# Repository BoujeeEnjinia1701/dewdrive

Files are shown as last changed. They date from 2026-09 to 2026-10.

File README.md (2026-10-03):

# DewDrive

     

**Area:** Water Security · **TRL:** 3 of 9 (proof of concept on paper) · **Value-engineering target:** $520 USD · **Difficulty:** 4 of 5

Solar-regenerated desiccant harvester that adsorbs moisture from air overnight and releases it into a passive condenser during the day.

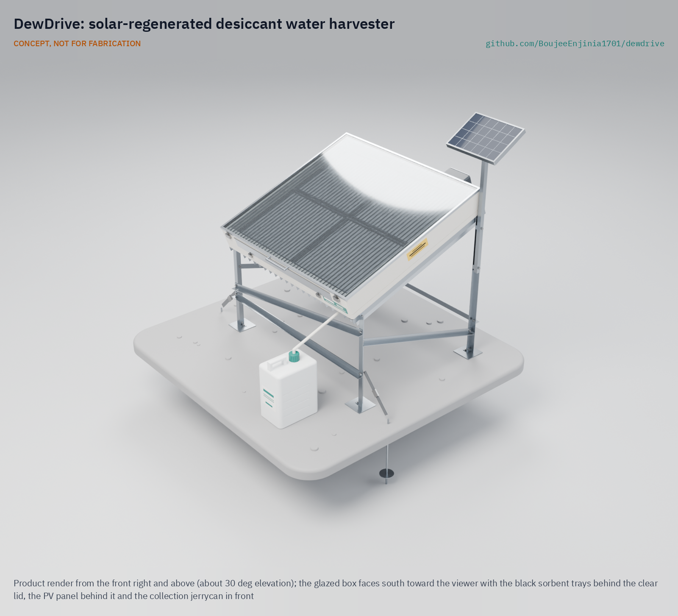
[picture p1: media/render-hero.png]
DewDrive: solar-regenerated desiccant water harvester, product render


[Exploded render](media/render-exploded.png) · [Detail render](media/render-detail.png) · [Interactive 3D model](media/viewer.html) · [Concept blueprint (PDF)](media/concept-blueprint.pdf) · [General arrangement DWD-DWG-001 (PDF)](cad/drawings/DWD-DWG-001.pdf) · [Sizing calculations](docs/04-calcs/01-sizing.md) · [Prototype build plan](docs/05-build-plan.md) · [Design decisions](docs/06-design-decisions.md) · [Review note](docs/REVIEW.md)

## Concept rationale

Cool desert nights are more humid than the days, and a salt-loaded desiccant can store that night-time moisture until the sun is strong enough to drive it out. DewDrive uses that daily rhythm directly: one glazed box that adsorbs at night and becomes a small solar still by day, with its own shaded floor as the condenser. It needs no compressor, no refrigerant and no grid, only a 2 W fan and the sun, and it keeps working at humidities where fog nets and dew condensers give nothing.

The design is open and garage-buildable on purpose. Silica gel and calcium chloride are sold as ordinary desiccants and food additives; the box is plywood, foam, polycarbonate and sheet aluminium; and the numbers behind every claim are in a script anyone can rerun. Commercial hydropanels are sealed products at about $2,000 each. An open design that a local workshop can build, repair and log lets communities and researchers compare real yields site by site.

## Burning platform

In 2022, 2.2 billion people still lacked safely managed drinking water, and 115 million collected untreated surface water from lakes, ponds, rivers and streams ([WHO, drinking-water fact sheet](https://www.who.int/news-room/fact-sheets/detail/drinking-water)). Over 2 billion people live in water-stressed countries, a pressure the WHO expects climate change and population growth to worsen in some regions (same source).

The cost falls hardest on the people who carry the water. UNICEF estimates that women and girls spend 200 million hours every day collecting it ([UNICEF, 2016](https://www.unicef.org/press-releases/unicef-collecting-water-often-colossal-waste-time-women-and-girls)). Even a supplementary half litre a day, made at the point of use, is water that nobody had to walk for.

## Where it could be used

### By industry

| Industry | Use |
| --- | --- |
| Humanitarian and WASH programs | Supplementary drinking water at schools, clinics and camps in arid areas, with logged yields to guide deployment |
| Agriculture and pastoralism | Drinking water at remote grazing posts and farm huts far from wells |
| Education and research | An open, instrumented test bed for sorbent and collector research across climates |
| Off-grid tourism and remote stations | Water for ranger posts, weather stations and eco-lodges supplied by truck |
| Emergency preparedness | A buildable backup source where wells or delivered supplies fail in drought |

### By country or region

| Country or region | Why it matters there |
| --- | --- |
| Navajo Nation, United States | About 30 % of homes lack running water, according to Navajo Nation Council Speaker Crystalyne Curley's testimony to the US Senate Committee on Indian Affairs on September 27, 2023 ([Senate Committee on Indian Affairs](https://www.indian.senate.gov/hearings/oversight-hearing-on-water-as-a-trust-resource-examining-access-in-native-communities/); [Native News Online](https://nativenewsonline.net/currents/senate-committee-on-indian-affairs-hears-30-of-navajo-nation-homes-lack-running-water)); a high-income country with households that haul water |
| Jordan | One of the most water-scarce countries in the world, with about 61 m³ of renewable water per person per year against a 500 m³ minimum ([UNICEF Jordan](https://www.unicef.org/jordan/water-sanitation-and-hygiene)) |
| Arid and semi-arid counties, Kenya | Access to safe water and basic sanitation is lowest in the arid and semi-arid land (ASAL) counties, where UNICEF focuses its water work with the government ([UNICEF Kenya](https://www.unicef.org/kenya/water-sanitation-and-hygiene)) |
| Rajasthan, India | In Thar Desert villages of northwest Rajasthan, water is scarce for up to 11 months of the year; women walk up to 4 km to fetch it, and villages store rainwater in underground taankas ([Al Jazeera, 2015](https://www.aljazeera.com/gallery/2015/11/19/women-lead-the-way-out-of-poverty-in-an-indian-desert)) |
| Atacama, Chile | In Alto Hospicio, only 1.6 % of informal settlements are connected to the water network and 75.4 % receive water by truck; researchers are assessing fog collection there as a complementary source ([Carter et al., *Frontiers in Environmental Science*, 2025](https://doi.org/10.3389/fenvs.2025.1537058)) |

## What sparked the idea

The starting point was a wartime device: the inflatable solar still that Mária Telkes developed at MIT during the Second World War for aircrews downed at sea. Seawater evaporated inside a balloon-like plastic envelope that folded into a package the size of a paper cup, and condensed again as drinkable water. The US government ordered 100,000 of them; by the summer of 1945 none had been delivered and the still was not used in the war, but solar stills later became part of military emergency kits ([USPTO, "A solar life"](https://www.uspto.gov/learning-and-resources/journeys-innovation/historical-stories/solar-life)). Telkes later patented a collapsible still, erected by inflation, as emergency equipment for the occupants of life rafts ([US Patent 3,415,719](https://patents.google.com/patent/US3415719A/en)). It showed that sunlight, a transparent envelope and a cool condensing surface can make drinkable water with no fuel at all. Telkes's still needed seawater. DewDrive asks what the same daytime still could do far from any sea, if a desiccant bed filled itself overnight from the desert air.

## Problem

Arid households without surface water or groundwater within reach depend on carried or trucked water; the air above them is an untapped supplementary source. Even desert air holds about 7 g of water per cubic metre on a 40 % RH night. Commercial solar hydropanels cost about $2,000 each and cannot be built or repaired locally. Design with, not for: requirements must come from co-design sessions and field trials with the intended users through a local partner.

Problem statement: [docs/01-problem.md](docs/01-problem.md)

## Concept

A glazed, insulated box 1.1 x 1.0 m, tilted 20° toward the sun, holds 4 kg of silica gel impregnated with 25 wt % calcium chloride in four sealed trays. At night the vent flaps are opened and a small solar-powered fan draws air in above the trays and down through the sorbent beds; the fan stops if the air goes above 70 % RH. By day the flaps are shut, the sun heats the sorbent to about 112 °C, and the vapour passes a black drip screen, condenses on the shaded, finned floor of the box and drains into a bottle. TRL 3 calculations ([DWD-CAL-001](docs/04-calcs/01-sizing.md)) for the design decided on 2026-09-25 ([DWD-DDR-002](docs/decisions/0002-recommendations-accepted.md)), made buildable in [DWD-DDR-003](docs/decisions/0003-design-for-construction.md), give:

| Quantity | Estimate |
| --- | --- |
| Water at 40 % night RH | about 0.57 L per day (target 0.5 L) |
| Water at 25 % night RH | about 0.45 L per day (target 0.25 L) |
| Mass | about 60 kg dry; box about 35 kg, 23 kg with the trays and deck lifted out |
| Parts cost | Estimated $639 for the buildable design, $119 over the $520 value-engineering target (a hypothetical control target, not a limit) |

One unit is a supplement: about one fifth of one person's survival drinking need.

Full design precis: [docs/02-concept.md](docs/02-concept.md)

## Key components

- Silica gel and calcium chloride composite sorbent in four black, sealed trays, with air drawn through the beds at night
- Drip screens with brine sumps under the trays
- Glazed, insulated solar box on a tilted steel stand
- Finned aluminium condenser forming the shaded floor of the box
- Night fan with a 10 W PV panel and a small LiFePO4 battery
- Humidity and temperature logging

The priced bill of materials is in [bom/bom.csv](bom/bom.csv). The parametric model is [cad/src/model.py](cad/src/model.py), with STEP files in `cad/step/`.

## Building the prototype

The prototype build plan ([docs/05-build-plan.md](docs/05-build-plan.md)) shows how to make each of the 31 components and put them together, with a making sketch for every made part, close-ups of the joints and a picture for every assembly step. Making the concept buildable added the parts that hold it together: battened wall panels, a lift-out tray deck that carries the drip screens, a fan hood that is now the only outlet, and a bolted, braced stand ([DWD-DDR-003](docs/decisions/0003-design-for-construction.md)). The water and heat results are unchanged; the parts now cost about $620, over the $520 value-engineering target, and the full box weighs 35.2 kg; Amish restated the portability requirement on 2026-10-02 for a lift with the trays and deck taken out (23.4 kg). Both are recorded in the [design decisions register](docs/06-design-decisions.md). It is a plan only: building and testing to it is TRL 4 work.

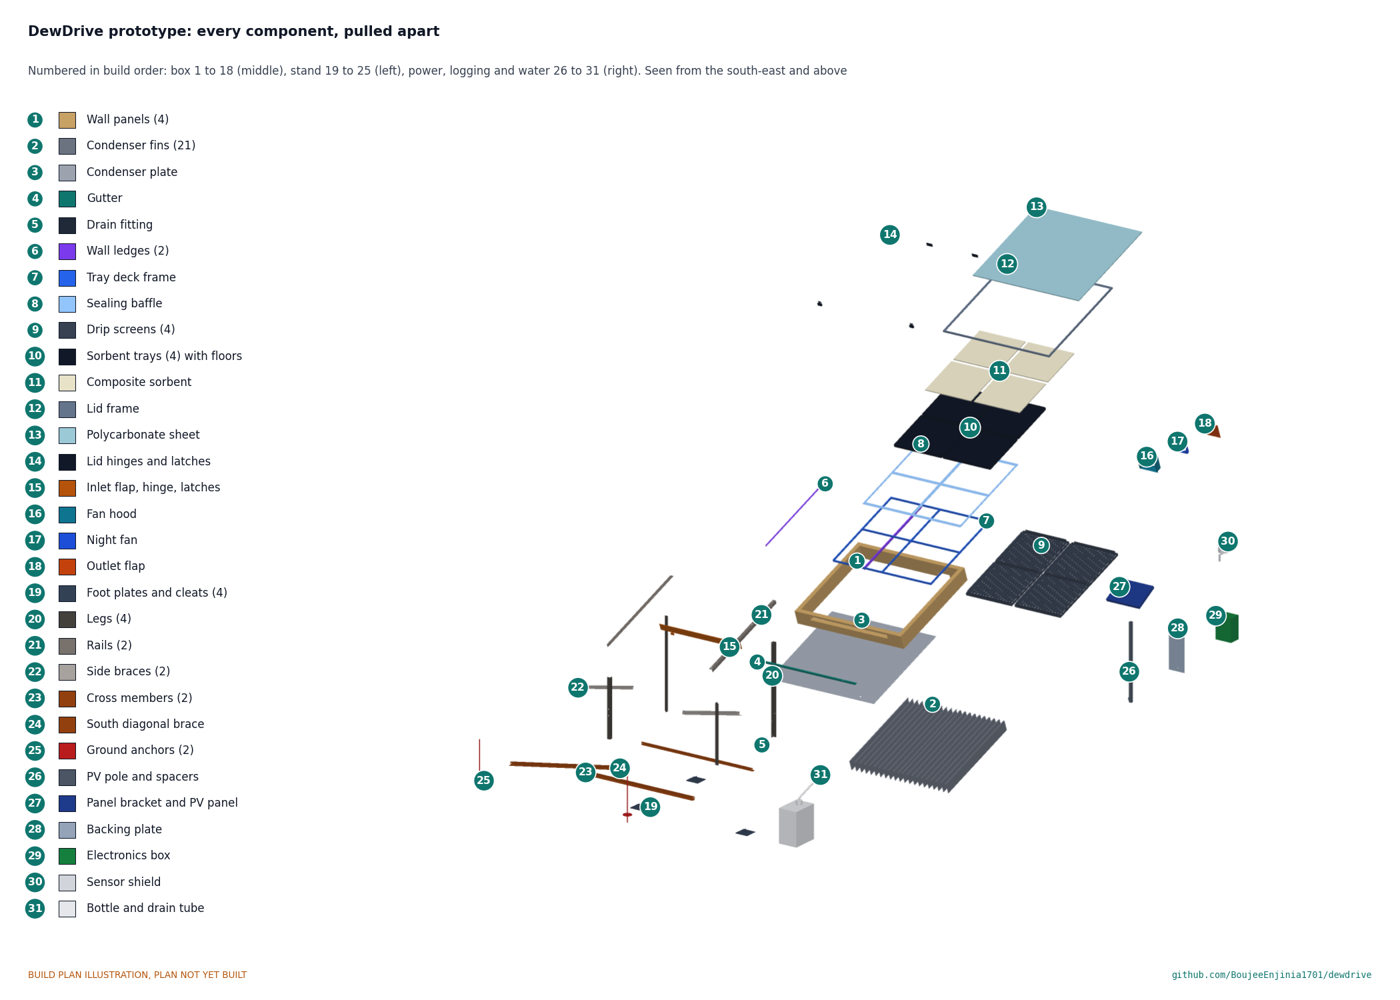
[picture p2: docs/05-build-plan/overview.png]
DewDrive prototype: every component pulled apart and numbered in build order


## Safety

> **Safety:** Harvested water must be tested and treated before drinking. The box interior and glazing get hot enough to burn, calcium chloride irritates eyes and skin, the small lithium iron phosphate battery must be fused, and the tilted panel must be held down with two ground anchors (or about 40 kg of ballast) against wind. See the safety section of the [design precis](docs/02-concept.md).

## Repository layout

| Folder | Contents |
| --- | --- |
| `docs/` | Problem, concept, requirements, calculations and design decisions |
| `cad/src/` | build123d Python source, the source of truth for all geometry |
| `cad/step/`, `cad/stl/` | Exported models for FreeCAD, other CAD tools and printing |
| `cad/drawings/` | 2D sketches and dimensioned drawings |
| `bom/` | Bill of materials |
| `electronics/` | KiCad schematics and PCB layouts |
| `firmware/` | Microcontroller code |
| `media/` | Renders, perspectives and photos |
| `build-log/` | Dated prototyping notes |

## Documentation

Controlled documents follow the portfolio [documentation standard](.kit/STANDARDS.md). Each carries a document ID (DWD-PRC-001 for the precis), a version and a revision history. Branded PDFs are built with `python .kit/render.py` and attached to GitHub Releases when a document is tagged, for example `DWD-PRC-001/v1.0`.

## Credits

Designed by Amish Chadha. See [CONTRIBUTORS.md](CONTRIBUTORS.md) for roles. To cite this design, use [CITATION.cff](CITATION.cff) (GitHub shows it as "Cite this repository").

AI assistance (Claude) was used to accelerate concept renders, prototype documentation and first-pass sizing calculations. Design direction and all decisions are Amish Chadha's, recorded in this repository's decision records (`docs/decisions/`).

## Licenses

- **Hardware** (CAD, drawings, BOM, electronics): [CERN-OHL-S v2](LICENSE)
- **Software** (firmware, scripts, notebooks): [MIT](LICENSE-SOFTWARE)

A project of the [Design Molecule](https://designmolecule.com) lab.

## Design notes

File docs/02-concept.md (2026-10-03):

---
doc_id: DWD-PRC-001
title: DewDrive design precis
project: DewDrive
doc_type: Design precis
version: "0.9"
status: Draft
date: '2026-10-02'
author: Amish Chadha
license: CERN-OHL-S-2.0
revisions:
- version: "0.1"
  date: '2026-09-24'
  author: Amish Chadha
  change: Initial scaffold
- version: "0.2"
  date: '2026-09-25'
  author: Amish Chadha
  change: Populate to TRL 2 (how it works, components, first-order numbers, design choices, safety, open questions, media)
- version: "0.3"
  date: '2026-09-25'
  author: Amish Chadha
  change: TRL 3 update (design choices decided by Amish in DWD-DDR-001; numbers replaced by DWD-CAL-001; parametric model and drawing DWD-DWG-001; yield shortfall and proposed fixes)
- version: "0.4"
  date: '2026-09-25'
  author: Amish Chadha
  change: Recommendations accepted by Amish (DDR-002); through-flow trays, 25 wt % salt, drip screens, fan humidity cut-out, anchors as default; numbers from DWD-CAL-001 v0.2
- version: "0.5"
  date: '2026-09-26'
  author: Amish Chadha
  change: Budget top-up approved by Amish
- version: "0.6"
  date: '2026-10-01'
  author: Amish Chadha
  change: "Design made constructable (DWD-DDR-003): tray deck, one outlet through the fan hood, bolted stand; mass and cost from DWD-CAL-001 v0.4"
- version: "0.7"
  date: '2026-10-01'
  author: Amish Chadha
  change: Budget treated as a value-engineering target
- version: "0.8"
  date: '2026-10-02'
  author: Amish Chadha
  change: 'Decisions of 2026-10-02 carried in (DWD-DEC-001 items 2 to 5): glazing rated 130 °C or more, stagnation vent study, R9 restated with lifting rule, first partner type'
- version: "0.9"
  date: '2026-10-02'
  author: Amish Chadha
  change: 'Follow-ups carried out: vent study concluded (low-emissivity screens dropped), label and 130 °C glazing in the BOM, cost USD 639 against the USD 520 target'
---

# DewDrive design precis

DewDrive is a glazed, insulated box 1.1 x 1.0 m, tilted 20° toward the sun on a steel stand. Inside, four black trays hold 4 kg of silica gel impregnated with 25 wt % calcium chloride. At night the vent flaps are opened and a 2 W fan draws air in above the trays and down through their mesh floors, and the sorbent takes up water. In the morning the flaps are shut; the sun heats the bed to about 112 °C by noon and drives the vapour down past a black drip screen onto a finned aluminium floor that forms the condenser, shaded by the box itself. The condensate runs down the slope into a gutter and a 10 L bottle. The TRL 3 calculation (DWD-CAL-001 v0.2) gives about 0.57 L per day at 40 % night RH and 0.45 L at 25 %, meeting the 0.5 and 0.25 L targets. The design follows Amish's decisions of 2026-09-25 (DWD-DDR-002), which replaced the v0.1 layout that made only 0.20 L per day. Made buildable in DWD-DDR-003, the estimated parts cost is $620 against the $520 value-engineering target (moved to $520 by Amish on 2026-09-26), $100 over the target. One unit supplements drinking water; it does not replace a water supply.

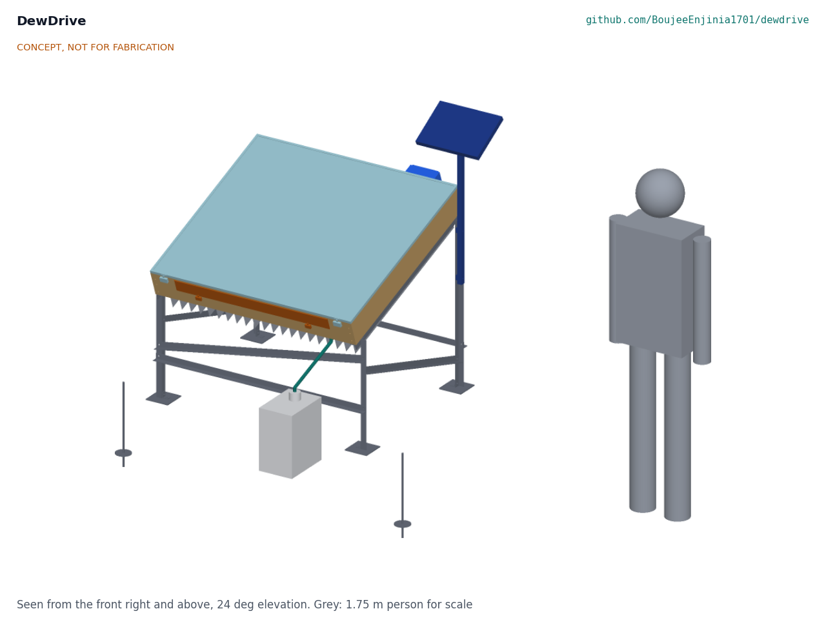
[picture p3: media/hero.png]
Hero render


*Figure 1. DewDrive on its stand, with a 1.75 m person for scale. Glazing faces south (for a northern-hemisphere site), the collection bottle sits below the low edge and the 10 W PV panel is on a pole to the north, where it cannot shade the box. Generated from the parametric model `cad/src/model.py`.*

## How it works

1. **Adsorb at night.** In the evening the user opens the south inlet flap, which sits above the tray deck, and the outlet flap over the fan on the north wall. The logger switches on the fan, which draws 40 m³/h of night air in over the trays, down through the 9.3 mm sorbent beds and their mesh floors, and out under the deck through a slot into the fan hood, for 10 h. The trays sit on an EPDM gasket on the sealing baffle of a lift-out deck, so the air cannot bypass the beds. The CaCl₂ in the silica gel pores binds water first as hydrates and then as a solution held in the pores; the silica gel adds a little uptake of its own and keeps the solution in place. If the air goes above 70 % RH the logger stops the fan.
2. **Seal and heat by day.** In the morning the user shuts both flaps. Sunlight passes through the twin-wall polycarbonate and heats the black top faces of the trays. The bed passes 89 °C by 09:00 and reaches about 112 °C at noon, and its vapour pressure rises above that of the condenser.
3. **Condense.** Vapour diffuses down through the 65 mm gap under the trays, around the drip-screen channels, to the aluminium floor plate, which stays within about 12 K of ambient thanks to 21 fins in the shade under the box.
4. **Collect.** Water films run down the 20° slope to a gutter along the low edge and drain through a silicone tube into a food-grade jerrycan.
5. **Log.** The logger records air temperature and RH, bed and condenser temperatures every 5 min, and applies the fan humidity cut-out; the user weighs the bottle each day. The data make yields comparable between sites.

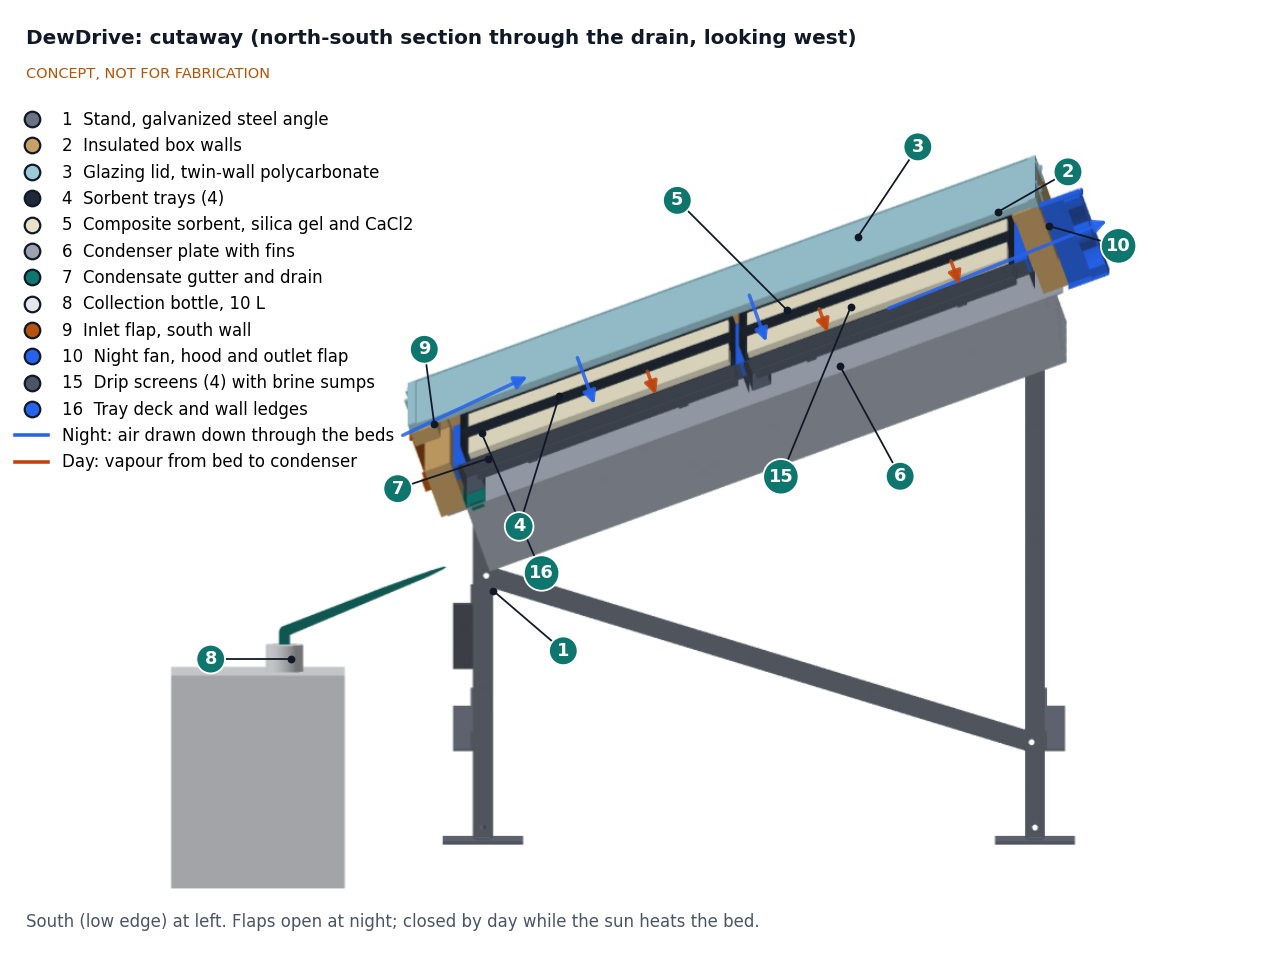
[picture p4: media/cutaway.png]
Cutaway


*Figure 2. North-south section through the drain, looking west. Blue arrows: night air path with the flaps open, in above the trays and down through the beds. Red arrows: daytime vapour path from the bed (5) past the drip screen (15) to the condenser floor (6). The gutter (7) along the low edge drains to the bottle (8).*

## Main components

Table 1. Main components. Numbers match `bom/bom.csv`, drawing DWD-DWG-001 and Figures 2 and 3.

| # | Component | Choice | Notes |
| --- | --- | --- | --- |
| 1 | Stand | Galvanized steel angle 30 x 30 x 3 mm, rails, legs, braces and cross members, bolted; tilt 20° | Separable from the box; two ground anchors by default, about 40 kg of ballast as the alternative (DWD-DDR-002, D13; DWD-CAL-001, H2 to H4) |
| 2 | Insulated box walls | Plywood skins with 25 mm PIR foam, 1,100 x 1,000 x 140 mm, 40 mm thick | Open top (glazing) and bottom (condenser) |
| 3 | Glazing lid | 10 mm UV-stabilized twin-wall polycarbonate, hinged on the north edge | Rated 130 °C or more; a 120 °C sheet only if supplier data and the inner skin measured at the TRL 4 stagnation test both show it stays inside its rating (DWD-DEC-001, item 3) |
| 4 | Sorbent trays (4) | Aluminium pans 490 x 430 x 25 mm with stainless mesh floors; black top, bare underside; EPDM edge gasket on a 1 mm aluminium sealing baffle | Lift out for recharging; the baffle forces the night air through the beds (D9) |
| 5 | Composite sorbent | 4 kg: 3.0 kg mesoporous silica gel with 1.0 kg CaCl₂ (25 wt %, D10) | Bed 9.3 mm deep on 0.785 m²; all food-grade |
| 15 | Drip screens (4) | Two staggered layers of 20 x 6 mm aluminium channels at 30 mm pitch under each tray, running down the slope to a closed brine sump; painted matt black | Catch any brine that leaves the beds (sumps 0.58 L in all) with no line of sight from bed to condenser (D11) |
| 6 | Condenser | 2 mm aluminium floor plate with 21 fins, 1 x 100 x 920 mm at 50 mm pitch | Wetted face food-safe coated |
| 7 | Gutter and drain tube | Gutter along the low edge; food-grade silicone tube | |
| 8 | Collection bottle | 10 L HDPE jerrycan | About 17 days of production at the design point |
| 9 | Vent flap, south inlet | Hinged flap 800 x 40 mm above the trays, with EPDM seal and latches | Closed by day; seal quality sets the vapour loss |
| 10 | Night fan, hood and outlet flap | 12 V 120 mm fan, about 2 W, in a hood over a slot in the north wall below the deck; the outlet flap closes the fan opening by day | Fan switched by the logger; stops above 70 % RH |
| 11 | PV panel | 10 W, 12 V, on a pole north of the box | Runs fan and logger |
| 12 | Electronics box | PWM charge controller, 12.8 V 6 Ah LiFePO4 with BMS, ESP32 logger | Only low-voltage DC on the device |
| 13 | Sensors | Air T and RH in a radiation shield; bed and condenser probes | The air RH reading drives the fan cut-out |

Item 14 (hardware and consumables) is in the BOM but not modelled. Item 16 is the lift-out tray deck with its sealing baffle and the wall ledges. The general arrangement is drawing DWD-DWG-001 Rev P4 (`cad/drawings/`); the STEP files are in `cad/step/`; how to build it is the build plan DWD-BLD-001 (`docs/05-build-plan.md`).

**Fan rule (DWD-DDR-002, D11).** The logger runs the fan from the evening flap opening for 10 h, and stops it whenever the air RH is above 70 % (restarting below about 65 %, to avoid cycling). This is a design rule for the firmware sketch; firmware beyond a sketch is TRL 4 work and on hold.

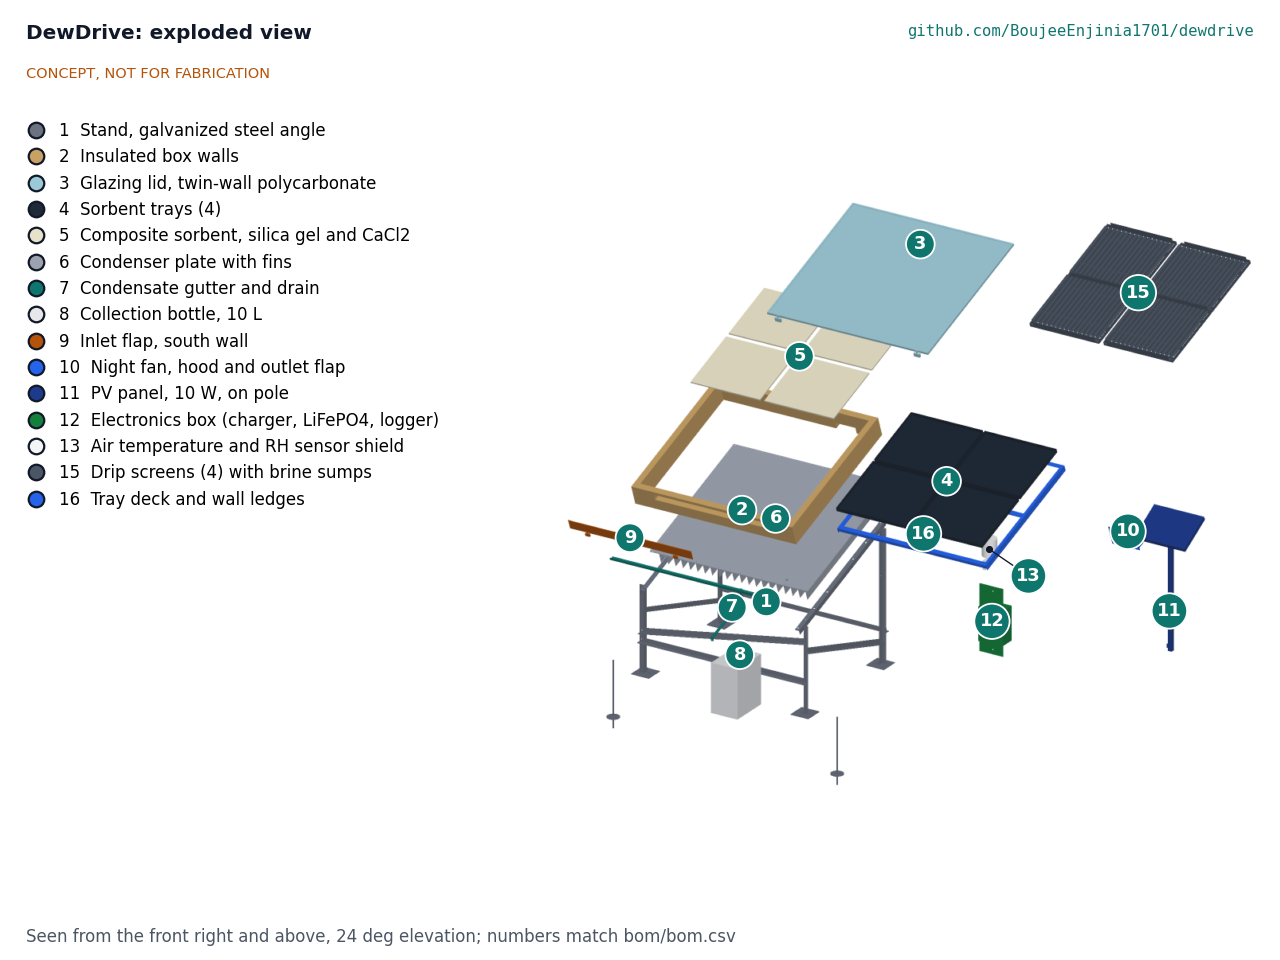
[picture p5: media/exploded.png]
Exploded view


*Figure 3. Exploded view with BOM numbers.*

## Numbers from DWD-CAL-001

All values are first-principles estimates from `docs/04-calcs/sizing.py` (DWD-CAL-001 v0.5); the tag after each value is the line of the script output that carries it. The sorbent isotherm is built from bulk salt data and must be replaced by measured isotherms of the actual composite.

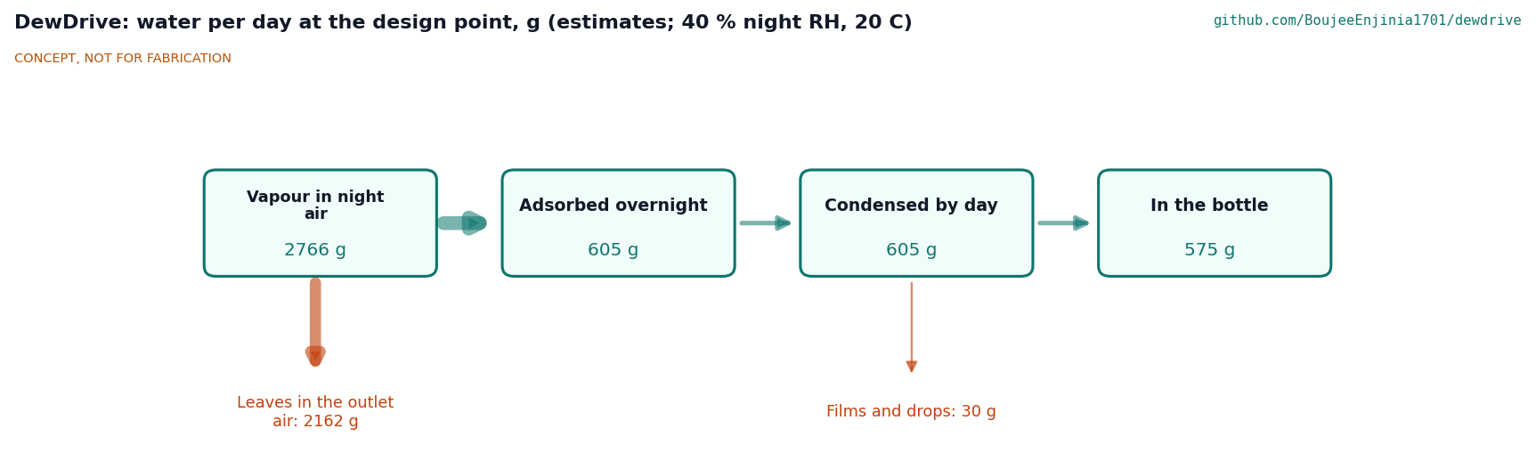
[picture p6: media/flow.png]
Water flow


*Figure 4. Water per day at the design point (40 % night RH, 20 °C). All values are estimates.*

Table 2. Water, energy, size and cost.

| Quantity | Value | Basis | Requirement |
| --- | --- | --- | --- |
| Vapour carried through the box overnight | 2.77 kg (B4) | 40 m³/h for 10 h at 6.92 g/m³ | |
| Share of the vapour driving force captured | Nearly all (gas-side NTU 19, B3) | Air drawn down through the bed; 0.16 Pa pressure drop | v0.1 layout: 11 % (B2) |
| Overnight uptake | 0.60 kg (B5) | Cyclic simulation; equilibrium would allow 1.59 kg (A4) | |
| Collected at 40 % night RH | 0.57 L per day (C3) | 0.60 kg condensed less 30 g of films | R1 met |
| Collected at 25 % night RH | 0.45 L per day (C4) | Same model | R2 met |
| Bed temperature at noon | 112 °C (C2) | 785 W/m² peak; 4.24 kWh/m² from 09:00 to 15:00 (C1) | R3 met |
| Condenser rise above ambient, peak | 12.1 K (C2) | Load 299 W peak; UA 24.6 W/K (C8) | R5 met |
| Where the sun goes | 3.68 kWh absorbed; 0.44 kWh desorbs water; 1.69 kWh lost through the glazing; 1.47 kWh to the condenser (C7) | The black drip screens cut the effective bed-to-condenser emissivity from 0.545 to 0.327 (C5) | |
| Solar-to-water efficiency | 7.1 % (C7) | Published devices reach about 9 % (LaPotin et al., 2021) | |
| Stagnation temperature, dry bed | 122 °C (D1) | Noon, 35 °C air | Glazing rated 130 °C or more (DWD-DEC-001, item 3) |
| Electrical use and supply | 23.6 Wh per day against 35 Wh (F1); 2.6 days of autonomy (F2) | Fan 2 W for 10 h; logger 0.15 W | R4 met |
| Salt containment | Pores fill above 71 % RH (E2); 43 % full after one 90 % RH night (E3) | Sumps 0.58 L (E6) | R7 met on paper |
| Mass | 60.2 kg (133 lb) dry; box 35.2 kg, 23.4 kg with the trays and deck lifted out (G1, G2) | Model components | R9 met as restated on 2026-10-02 (lift with the trays and deck out) |
| Wind at 20 m/s | 317 N normal to the lid; tips without two anchors or 40 kg of ballast (H1 to H4) | Force coefficient 1.2 on 1.1 m² | R10 not verifiable at TRL 3 |
| Parts cost | $639 (J1) | `bom/bom.csv` | R11 over the value-engineering target by $119 (target $520) |
| Water per dollar over 5 years | about $0.49 per litre (J2) | Parts only | For comparison |

What the numbers say:

- **Drawing the air through the bed fixes the yield.** The v0.1 layout, with air skimming past the trays, captured only 11 % of the vapour driving force and made 0.20 L per day. Through the bed, the air leaves close to equilibrium with the sorbent, and the day desorption now sets the limit. Even if slow diffusion inside the grains cut the night NTU to 1, the yield would still be 0.53 L per day (C9).
- **The drip screens help the yield.** Black channels under the trays catch brine and also cut the radiation from the hot beads to the condenser by about 40 %: 0.57 L per day with them against 0.51 L without (C6).
- **A low-emissivity screen would do more, but overheats the box.** Bare aluminium channels would give 0.82 L per day, but a dry bed would stagnate at about 166 °C, beyond the rating of polycarbonate glazing (C10, D1). That option is not adopted. Amish decided on 2026-10-02 (DWD-DEC-001, item 4) on one short paper study of a passive stagnation vent. The study (DWD-CAL-001, section D) finds that a vent of about 117 cm² would hold the dry bed at 122 °C, but it would have to stay shut in normal operation, when the bed already runs at 130 to 149 °C, so it needs a thermostat and is not passive or modest in cost. The low-emissivity screens are therefore dropped and the prototype keeps the black screens.
- **The lower salt loading contains the brine.** At 25 wt % the solution fills the pores only above 71 % RH, against 51 % RH at the v0.1 loading (E2).
- **Cost is over the value-engineering target once the design is buildable.** The gasket, baffle and drip screens added $27 (total $515, D15); the parts that make the design buildable (DWD-DDR-003) bring the estimated cost to $620; the 2026-10-02 decisions add a glazing sheet rated 130 °C or more and a label, making $639 against the $520 target ($119 over).
- **Yield is still modest.** About 0.57 L per day is about one fifth of one person's survival drinking need.

## Key design choices

Choices 1 to 7 were decided by Amish on 2026-09-25 (DWD-DDR-001, going with the recommendation), and choices 8 to 11 on the same day (DWD-DDR-002). Choice 12 was part of the design from the start.

1. **Single-stage, flat glazed box** rather than a dual-stage or tubular design (D4). Dual-stage could add about 20 % in later versions (LaPotin et al., 2021).
2. **Silica gel and CaCl₂ composite**, rather than MOF, zeolite or LiCl (D3), at 25 wt % salt (D10, amending the 33 wt % of D3).
3. **Condenser as the shaded floor of the box**, directly below the bed (D4). Short vapour path, no pump, one fewer seal.
4. **Fan-assisted night airflow** with a 10 W PV panel and a 12.8 V LiFePO4 battery, rather than natural airflow (D5).
5. **Manual flaps** opened and closed by the user, rather than automatic actuators (D6).
6. **20° tilt, fixed**, facing the equator, with twin-wall polycarbonate glazing rather than glass (D7).
7. **Design point** of 20 °C and 40 % RH at night and 6.0 kWh/m² of sun, with a 25 % RH low-humidity case (D8).
8. **Night air drawn down through the sealed trays** (D9), with the inlet flap above the trays and the fan below them.
9. **Drip screens and a fan humidity cut-out** for wet spells (D11). The screens are black, not low-emissivity, after the paper evaluation of D12.
10. **Two ground anchors by default**, ballast as the alternative (D13).
11. **Value-engineering target kept at $500** (D14), then moved to $520 by Amish on 2026-09-26 (D15) once the BOM reached $515.
12. **Built-in logging** so that each prototype yields comparable data.

## Safety

> **Safety:** Harvested water must be tested and treated before drinking. Condensed water is close to distilled, but it can pick up bacteria, dust, salt from the sorbent and metal from the condenser. Until a laboratory test shows otherwise, boil or disinfect it and do not use it as the only drinking source. Distilled-like water also lacks minerals.

> **Safety:** The inside of the box gets hot enough to burn: an estimated 112 °C in the bed at noon and about 122 °C with a dry bed (DWD-CAL-001 v0.2, C2 and D1). The glazing outer skin reaches about 57 °C and the condenser fins about 47 °C. Open the lid only when cool, wear gloves when handling trays and drip screens, and label the glazing. The polycarbonate must be rated 130 °C or more (DWD-DEC-001, item 3); a 120 °C sheet is acceptable only if the supplier's data and the inner-skin temperature measured at the TRL 4 stagnation test both show it stays inside its rating. Do not fit bare, low-emissivity screens: they would raise the dry bed to about 166 °C.

> **Safety:** Calcium chloride irritates eyes and skin and gives off heat when it dissolves. Wear gloves and eye protection when preparing the sorbent and when emptying the drip-screen sumps. At 25 wt % the solution fills the pores only above about 71 % RH (DWD-CAL-001, E2); the fan stops above 70 % RH and the drip screens catch any brine. Keep trays level, close the flaps in rain, and never let the solution reach the water path.

> **Safety:** The 12.8 V LiFePO4 battery has a built-in BMS and must be fused at the battery. Keep the electronics box shaded, and do not charge a damaged or swollen battery.

> **Safety:** The tilted lid catches the wind like a sail (317 N at 20 m/s). Without restraint the unit tips over (DWD-CAL-001, H2). Fit the two ground anchors, or about 40 kg of ballast, before the box goes on the stand. Empty the box of its trays and deck before lifting it; it carries a label saying so (R9 as restated, DWD-DEC-001, item 2). Deburr all aluminium fins, channels and sheet edges; fins under the box are at ankle and hand height.

## Open questions

- [ ] What are the measured uptake isotherms and rates of the 25 wt % composite at 20 °C and at 80 to 120 °C? These set every yield number.
- [x] How can the parts cost come back to $500, or should the value-engineering target move? Decided by Amish, 2026-09-26: target moved to $520 (DWD-DDR-002, D15).
- [ ] Can a passive stagnation vent hold a dry bed near 122 °C at a modest cost? Decided by Amish, 2026-10-02 (DWD-DEC-001, item 4): one short paper study; if it cannot, the low-emissivity screens are dropped.
- [x] Glazing rating with a 122 °C dry bed. Decided by Amish, 2026-10-02 (DWD-DEC-001, item 3): rated 130 °C or more, or a 120 °C sheet only with supplier data and a measured inner-skin temperature at the TRL 4 stagnation test.
- [ ] How much salt carries over into the condensate, and does the aluminium condenser need a coating or a stainless replacement?
- [ ] How well do simple flap and tray seals hold, by night against bypass air and by day against vapour loss?
- [ ] Which site provides the humidity and solar data for the design point? Partner type decided by Amish, 2026-10-02 (DWD-DEC-001, item 5): the first candidate to approach, not yet agreed, is a university dryland field station in a hot semi-arid region with night humidity of about 25 to 40 % and an existing weather record, with a water and sanitation NGO for the later community trial.

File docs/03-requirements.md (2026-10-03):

---
doc_id: DWD-REQ-001
title: DewDrive requirements
project: DewDrive
doc_type: Requirements
version: "0.9"
status: Draft
date: '2026-10-02'
author: Amish Chadha
license: CERN-OHL-S-2.0
revisions:
- version: "0.1"
  date: '2026-09-24'
  author: Amish Chadha
  change: Initial scaffold
- version: "0.2"
  date: '2026-09-25'
  author: Amish Chadha
  change: First measurable requirements for TRL 2, with a design point and concept status
- version: "0.3"
  date: '2026-09-25'
  author: Amish Chadha
  change: TRL 3 update (design point and budget decided by Amish in DWD-DDR-001; R11 redefined to $500; status column from DWD-CAL-001)
- version: "0.4"
  date: '2026-09-25'
  author: Amish Chadha
  change: Recommendations accepted by Amish (DDR-002); R7 restated for the drip screens; R8 and R10 wording; status from DWD-CAL-001 v0.2
- version: "0.5"
  date: '2026-09-26'
  author: Amish Chadha
  change: Budget top-up approved by Amish (R11 target $520; status from DWD-CAL-001 v0.3)
- version: "0.6"
  date: '2026-10-01'
  author: Amish Chadha
  change: Status from DWD-CAL-001 v0.4 for the constructable design (DWD-DDR-003); R9 and R11 not met, open for Amish
- version: "0.7"
  date: '2026-10-01'
  author: Amish Chadha
  change: Budget treated as a value-engineering target
- version: "0.8"
  date: '2026-10-02'
  author: Amish Chadha
  change: R9 restated by Amish on 2026-10-02 for a lift with the trays and deck taken out, with an empty-before-lifting label (DWD-DEC-001, item 2); R9 met
- version: "0.9"
  date: '2026-10-02'
  author: Amish Chadha
  change: Status from DWD-CAL-001 v0.7 (script re-run; R9 met as restated); R11 over the target by $119 after the 130 °C glazing and the label
---

# DewDrive requirements

These requirements were checked by calculation at TRL 3 in DWD-CAL-001 v0.7, for the design decided by Amish on 2026-09-25 (DWD-DDR-002) as made buildable in DWD-DDR-003: night air drawn down through the sealed trays, 25 wt % CaCl₂, a drip screen under each tray and a fan cut-out above 70 % RH. The design meets ten of thirteen. Making it buildable added parts: R11 (cost) is over its value-engineering target, at an estimated $639 against $520, and R9 (portability) was not met as first written, the full box being 35.2 kg against 35 kg. Amish restated R9 on 2026-10-02 for a lift with the trays and deck taken out (DWD-DEC-001, item 2), and it is met at 23.4 kg. The design decisions register (DWD-DEC-001) lists R11's cost drivers and savings. R6 and R10 can only be verified by test. The yield targets R1 and R2, missed by the v0.1 design, are now met. Targets are still proposals for review, not user-validated needs, and will be revised after co-design sessions.

## Design point

Decided by Amish on 2026-09-25 (DWD-DDR-001, D8). Unless a requirement says otherwise, it applies at this design point:

- Night: 10 h adsorption at 20 °C air and 40 % RH (6.92 g/m³ of vapour).
- Day: 6.0 kWh/m² of sun on the tilted aperture, of which 4.24 kWh/m² falls in the 09:00 to 15:00 window (DWD-CAL-001, C1); air at 35 °C.
- Low-humidity case: night air at 20 °C and 25 % RH, same sun.

## Requirements

Table 1. Requirements and TRL 3 status. Values and tags are from DWD-CAL-001 v0.5, Table 4.

| ID | Requirement | Target | Verification | TRL 3 status |
| --- | --- | --- | --- | --- |
| R1 | Produce water at the design point | 0.5 L per day or more collected, per unit | Cyclic mass and heat balance (DWD-CAL-001); later field test | Met: 0.57 L per day (C3); v0.1 design 0.20 L |
| R2 | Produce water in dry nights | 0.25 L per day or more at 25 % night RH | Same | Met: 0.45 L per day (C4); v0.1 design 0.09 L |
| R3 | Use only the sun for regeneration | No fuel or grid power; bed reaches 75 °C or more by midday on a clear day at 35 °C ambient | Collector heat balance | Met: bed about 112 °C at noon (C2) |
| R4 | Run its own electrical loads | Fan and logger need 30 Wh per day or less, supplied by the on-board PV panel, with 2 days or more of battery autonomy | Energy budget | Met: 23.6 Wh per day against 35 Wh per day; 2.6 days of autonomy (F1, F2) |
| R5 | Keep the condenser cool | Condenser 15 K or less above ambient at the peak of desorption | Condenser heat balance | Met: 12.1 K (C2) |
| R6 | Keep the water clean | All wetted parts food-grade; no salt carry-over (chloride in the collected water below 250 mg/L) | Materials review; later laboratory water test | **Not verifiable at TRL 3.** Materials chosen to meet it |
| R7 | Contain the salt | No liquid CaCl₂ solution leaves the tray and drip-screen assembly or reaches the condenser, even after a night at 90 % RH (restated by DWD-DDR-002, D11; was "leaves the trays") | Pore volume against solution volume; sump volume; later chamber test | Met on paper: the pores fill only above 71 % RH (E2); one 90 % RH night fills 43 % of them (E3), three in a row 50 % with the fan rule and 63 % without it (E4, E5); the sumps hold 0.58 L as a backstop (E6) |
| R8 | Be simple to operate | Two user actions per day (open flaps in the evening, close them in the morning), 5 min per day or less | Task analysis; co-design sessions | Met by design; the fan timer and humidity cut-out need no user action |
| R9 | Be portable and quick to set up | Box 35 kg or less when lifted with the trays and deck taken out (two-person lift), and labelled to be emptied before lifting; stand separable; set up by two people in 30 min or less. Restated by Amish on 2026-10-02 (DWD-DEC-001, item 2; DWD-DDR-003, A2); was "box 35 kg or less" | Mass from model components; later trial | Met: 23.4 kg with the trays, sorbent, deck and screens lifted out; 35.2 kg with everything inside; total 60.2 kg (G1, G2). Set-up time needs a trial |
| R10 | Survive the site | Stable in 20 m/s (72 km/h) wind with two ground anchors (default, DWD-DDR-002, D13) or ballast; UV-stable glazing; sorbent 300 cycles or more with 20 % or less loss of capacity | Wind load calculation; supplier data; later cycling test | **Not verifiable at TRL 3.** Wind: two anchors of 98 N each, or 40 kg of ballast (H2 to H4) |
| R11 | Cost | Parts $520 or less (`project.yaml` value-engineering target, moved from $400 to $500 by Amish on 2026-09-25, DWD-DDR-001 D1, and to $520 on 2026-09-26, DWD-DDR-002 D15) | Priced BOM | **Over the value-engineering target by $119:** $639 (J1) against $520; the buildable design added parts (DWD-DDR-003) and the decisions of 2026-10-02 added a 130 °C glazing sheet and the label |
| R12 | Record performance | Log air temperature and RH, bed and condenser temperature every 5 min for 30 days or more; daily water mass recorded by weighing | Storage estimate; design review | Met: 8,640 records, 0.41 MB (I1) |
| R13 | Protect users | External surfaces a person would touch in normal use stay at 60 °C or less; the glazing is labelled hot; no exposed conductor above 60 V DC | Surface temperature estimate; design review | Met: glazing outer skin about 57 °C at stagnation, fins up to 47 °C (D2, D3); 12.8 V DC |

## Assumptions

- The composite (25 wt % CaCl₂: 1.0 kg in 3.0 kg of mesoporous silica gel) is modelled from bulk salt thermodynamics: at equilibrium it holds 0.397 g/g at 40 % RH and 0.258 g/g at 25 % RH (DWD-CAL-001, A4). The yield is set by how fast the bed takes up and gives off water, not by these capacities. Measured isotherms and uptake rates of the actual composite must replace the model.
- The day ends with the salt dried to about the dihydrate; the night starts with the bed at air temperature.
- With the fan stopped above 70 % RH, natural airflow through the open flaps is taken as 4 m³/h (10 % of the fan flow); this is an assumption to check by test.
- One unit is a supplement: about 0.57 L per day is about one fifth of one person's survival drinking need of 2.5 to 3 L per day (WHO technical note 9).

> **Safety:** Requirements R6, R7, R10 and R13 exist because of hazards: untreated water, a corrosive salt solution, wind loads on a 1.1 m² panel, and hot surfaces. They cannot be waived without a documented decision by Amish.

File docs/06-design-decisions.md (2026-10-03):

---
doc_id: DWD-DEC-001
title: DewDrive design decisions register
project: DewDrive
doc_type: Design decisions register
version: "0.4"
status: Draft
date: '2026-10-02'
author: Amish Chadha
license: CERN-OHL-S-2.0
revisions:
- version: "0.1"
  date: '2026-10-01'
  author: Amish Chadha
  change: Register opened with the open decisions from the review note, DWD-DDR-001 to DWD-DDR-003 and the build plan work
- version: "0.2"
  date: '2026-10-01'
  author: Amish Chadha
  change: Budget treated as a value-engineering target
- version: "0.3"
  date: '2026-10-02'
  author: Amish Chadha
  change: Amish approved the recommendations of open items 1 to 6 on 2026-10-02; all moved to decisions made; glazing rating line updated
- version: "0.4"
  date: '2026-10-02'
  author: Amish Chadha
  change: Follow-ups carried out; vent study result recorded (low-emissivity screens dropped); cost USD 639 against the USD 520 target
---

# DewDrive design decisions register

Every design decision still to be made, and every decision made, in one place. Each decision is argued in full in its decision record under `docs/decisions/`; this register is the index Amish works from. The build plan (`docs/05-build-plan.md`) describes the design as it stands and does not list open decisions.

## Open decisions

None. All open decisions were decided on 2026-10-02.

## To confirm when parts are bought

| # | What to confirm | Why it matters | Source |
| --- | --- | --- | --- |
| 1 | The silica gel is a grade that does not crack in liquid water (sold as water-resistant or for impregnation), with about 1.0 cm³/g pore volume | Ordinary silica gel can shatter when the salt solution is poured on it; the pore volume sets the salt containment | Build plan, section 3.8; DWD-CAL-001, E1 |
| 2 | The polycarbonate sheet is rated 130 °C or more (decided 2026-10-02), or, for a 120 °C sheet, that the supplier's data and the inner-skin temperature measured at the TRL 4 stagnation test both show it stays inside its rating; and that the U-channel fits its 10 mm edge | A dry bed stagnates near 122 °C; the frame holds the sheet | Build plan, section 3.9; decision of 2026-10-02 (open item 3) |
| 3 | High-temperature epoxy rated 120 °C or more, and a food-safe coating for aluminium | The fins' bond and the wetted face see condenser temperatures and the water | Build plan, section 3.2 |
| 4 | The bulkhead fitting suits a 17 mm hole and its nut clears the fins (31 mm or less across) | It sits between two fins 50 apart | Build plan, section 3.3 |
| 5 | The 120 mm fan fits the hood front's 114 mm hole and its four corner screws | Sets the hood hole | Build plan, section 3.11 |
| 6 | The ground anchors hold 100 N or more of uplift in the site's soil | DWD-CAL-001, H4 asks for 98 N each | Build plan, section 3.19 |
| 7 | The electronics box is about 160 x 110 x 220 and holds the controller, battery and logger | Sets the backing plate and hole pattern | Build plan, section 3.18 |
| 8 | The tray deck sags no more than the gasket can take (about 3 mm at the centre by hand calculation) | If the tray lips lift, use a deeper bar | DWD-DDR-003, P3 |

## Value engineering

Value-engineering target: USD 520 (a hypothetical control target, not a limit). Estimated cost of the constructable design: USD 639 (USD 119 over the target). The estimate was USD 515 before the design for construction.

Main cost drivers (the parts added to make the design buildable): the tray deck and wall ledges (USD 35), the lid's U-channel frame, hinges and latches priced in full (USD 15 more), wall battens, inserts and paint (USD 13 more), trays with a perforated floor under the mesh (USD 10 more), a proper drain fitting (USD 7), fixings (USD 7), pole, bracket and backing plate (USD 6), fin feet, rivets and epoxy (USD 4), screen frames (USD 4), stand bracing, foot plates and straps (USD 3) and the fan hood (USD 1). The decisions of 2026-10-02 added a glazing sheet rated 130 °C or more (USD 17 more, an estimate without a supplier quote) and the "Empty before lifting" label (USD 2). Over 5 years at the design point the parts cost about USD 0.61 per litre of water.

Savings worth trying: a single 1.5 mm strap size and offcut sheet for the deck and screens (about USD 15), a cheaper panel bracket and backing plate (about USD 5), and a timer-only fan switch in place of the logger (about USD 15, but it loses R12). Together these still leave the design over the target.

## Decisions made

| Date | Decision | Decided by | Record |
| --- | --- | --- | --- |
| 2026-09-25 | TRL 2 review items D1 to D8: value-engineering target raised to $500; problem wording; silica gel and CaCl₂ composite; single-stage flat box with the condenser as its floor; fan-assisted night airflow with a 10 W panel and LiFePO4 battery; manual flaps; fixed 20° tilt and twin-wall polycarbonate; design point | Amish: go with recommendation | DWD-DDR-001 |
| 2026-09-25 | TRL 3 items D9 to D14: night air drawn down through sealed trays; 25 wt % salt; drip screens and a fan cut-out above 70 % RH; low-emissivity screen evaluated on paper; ground anchors as default restraint; value-engineering target kept at $500 | Amish: "i accept all your recommendations, go with them across all repos." | DWD-DDR-002 |
| 2026-09-25 | TRL 4 on hold; `trl_target` stays 3 | Amish | `project.yaml` |
| 2026-09-26 | Value-engineering target moved to $520 (D15) | Amish: "I am ok with the budget top ups" | DWD-DDR-002 v0.2 |
| 2026-09-30 | Make the design physically buildable while drawing the build plan | Amish: "If you are realising that the design cannot be built as per concept - fix the design assumptions to match and be physically feasible as you draw the illustrations." | DWD-DDR-003 (changes made under this instruction; accepted on 2026-10-02, below) |
| 2026-09-30 | Open decisions are kept in this register, not in the build plan | Amish: "don't log outstanding decisions in this build plan - that is not the place for it. that should be in a separate design document logged and named as such" | `.kit/STANDARDS.md`, section 18 |
| 2026-10-02 | Open item 1: design for construction accepted: the changes P1 to P13 and their knock-on changes, as made | Amish: "i approve your recommendations for all 555 open decisions." | DWD-DDR-003, Tables 1 and 2 |
| 2026-10-02 | Open item 2: R9 restated as a box of 35 kg or less when lifted with the trays and deck taken out (23.4 kg, met); the box is labelled to be emptied before lifting | Amish: "i approve your recommendations for all 555 open decisions." | DWD-DDR-003, A2; DWD-CAL-001, G1, G2 |
| 2026-10-02 | Open item 3: glazing is twin-wall polycarbonate rated 130 °C or more; a 120 °C sheet is accepted only if the supplier's data and the inner-skin temperature measured at the TRL 4 stagnation test both show it stays inside its rating | Amish: "i approve your recommendations for all 555 open decisions." | DWD-DDR-002, O5 |
| 2026-10-02 | Open item 4: one short paper study of a passive stagnation vent; if it cannot hold a dry bed near 122 °C at a modest cost, the low-emissivity screens are dropped. The first prototype keeps black screens | Amish: "i approve your recommendations for all 555 open decisions." | DWD-DDR-002, O4 |
| 2026-10-02 | Open item 5: first partner, the first candidate type to approach (not yet agreed), is a university dryland field station in a hot semi-arid region with night humidity of about 25 to 40 % and an existing weather record, with a water and sanitation NGO for the later community trial | Amish: "i approve your recommendations for all 555 open decisions." | DWD-DDR-001, O1 |
| 2026-10-02 | Open item 6: the five appearance model deviations are accepted, and the appearance model and renders are to be updated to the constructable design on Amish's Mac | Amish: "i approve your recommendations for all 555 open decisions." | `docs/REVIEW.md`, session 2026-09-26 |
| 2026-10-02 | Result of the vent study of open item 4: a passive vent cannot hold a dry bed near 122 °C at a modest cost (it needs about 117 cm² and must stay shut in normal operation), so the low-emissivity screens are dropped and the black screens stay | Applies Amish's 2026-10-02 decision of open item 4 to the study result | DWD-CAL-001 v0.7, section D (D4, D5) |

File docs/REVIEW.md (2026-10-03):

# Review note: DewDrive

## Session 2026-09-25: /populate to a strong TRL 2 (overnight batch run)

### What was done

- `docs/01-problem.md` (DWD-PRB-001 v0.2): problem, users, operating environment, constraints, out of scope, prior work with inline sources (MOF, zeolite and salt-composite harvesters, commercial hydropanels, WHO water needs), open questions. There was no co-design checklist to keep.
- `docs/03-requirements.md` (DWD-REQ-001 v0.2): a stated design point and 13 measurable requirements (R1 to R13), each with a concept status.
- `docs/02-concept.md` (DWD-PRC-001 v0.2): how it works, 13 numbered components, first-order water, heat, electrical, mass, wind and cost numbers with assumptions, eight design choices, safety section, open questions.
- `cad/src/concept_media.py`: massing model of the tilted glazed box (walls, glazing, four trays, sorbent bed, finned condenser floor, gutter and drain, flaps, fan), stand, bottle, PV pole, electronics box and sensor shield, each with its BOM number. It places the 1.75 m person by hand so the figure never overlaps the collector, and draws its own north-south cutaway with computed callouts and air and vapour arrows.
- `media/`: `hero.png`, `concept-blueprint.png`, `.pdf` and `.svg`, `model.glb` and `viewer.html`, `exploded.png` (callouts 1 to 13), `cutaway.png`, `flow.png` (daily water mass balance, all values labelled as estimates). Temporary `media/_views*` folders are deleted by the script.
- `bom/bom.csv`: 14 lines with indicative USD prices, numbered to match the exploded view; `bom/bom-notes.md` gives the group totals and the budget gap.
- `README.md`: hero image and links line before "## Problem"; problem, concept, key components and safety updated to match the concept.
- `docs/pdf/`: branded PDFs of the three controlled documents.
- `project.yaml`: unchanged.

### Key results (estimates, to be checked at TRL 3)

| Quantity | Estimate | Requirement |
| --- | --- | --- |
| Water at 40 % night RH, 20 °C | about 0.49 L per day (range 0.35 to 0.6) | R1 met, no margin |
| Water at 25 % night RH | about 0.25 L per day | R2 at risk |
| Yield per aperture area | about 0.5 L/m² per day | Published devices: 0.74 to 0.77 at 60 to 68 % RH |
| Bed temperature by midday | 80 to 90 °C | R3 met by estimate |
| Heat available versus needed | about 2 kWh versus 0.5 kWh | Condenser limits yield |
| Condenser rise above ambient | about 12 K | R5 met by estimate |
| Solar-to-water efficiency | about 5 % | |
| Electrical use versus PV supply | about 24 versus 35 Wh per day | R4 met, thin margin |
| Mass | about 45 kg dry; box about 30 kg | R9 met by estimate |
| Wind uplift at 20 m/s | about 330 N | R10 needs anchors or ballast |
| Parts cost | about $475 | **R11 not met**, about 19 % over $400 |

Requirements not met or at risk:

- **R11 (cost) not met:** about $475 against $400.
- **R2 (dry-night yield) at risk:** about 0.25 L per day meets the target only at the nominal estimate; the CaCl₂ uptake below about 30 % RH is uncertain.
- **R1 has no margin:** every yield number rests on estimated sorbent isotherms that must be measured.
- **R6 (water quality) and R7 (salt containment) cannot be verified at TRL 2;** R10 (wind, UV, cycle life) is unverified.

### Proposed, awaiting Amish

1. **Budget.** Options: (a) raise `budget_usd` to $500 for a research prototype with fan and logging; (b) a fanless version with natural night airflow and USB power-bank logging, about $400, lower and slower uptake; (c) cut cost elsewhere (plain plywood without foam, cheaper glazing), which costs yield. Recommendation: (a), because the logged data are the main output of the first prototype. `project.yaml` is unchanged.
2. **Problem and pitch wording.** The `project.yaml` problem ("no water source at all") implies DewDrive could be a sole supply, but one unit gives about one fifth of one person's survival drinking need. Options: keep it; or reword it to, for example, "Arid households without surface water or groundwater within reach depend on carried or trucked water; the air above them is an untapped supplementary source." Recommendation: reword, keeping the meaning. Both fields are unchanged in `project.yaml`; the README keeps the original sentence and adds context.
3. Sorbent: silica gel with about 33 wt % CaCl₂, rather than LiCl composites, zeolite or MOF.
4. Single-stage flat glazed box with the condenser as the shaded floor, rather than dual-stage or a separate condenser.
5. Fan-assisted night airflow with a 10 W PV panel and a 12.8 V LiFePO4 battery, rather than natural airflow.
6. Manual flaps, rather than automatic actuators.
7. Fixed 20° tilt facing the equator; twin-wall polycarbonate glazing rather than glass.
8. Design point: 20 °C and 40 % RH at night, 6.0 kWh/m² of sun; low-humidity case 25 % RH.
9. First partner and region for co-design, which will also supply the site climate data.

### Safety concerns

- Untreated water: possible bacteria, salt carry-over and aluminium from the condenser. The documents require testing and treatment before drinking.
- Hot surfaces: bed about 80 to 90 °C, higher at stagnation with an empty bed; the polycarbonate rating must cover it.
- Calcium chloride: eye and skin irritant, exothermic on dissolving, and a corrosive solution if the bed over-saturates.
- LiFePO4 battery: BMS, fuse at the battery, shaded mounting.
- Wind: about 330 N on the tilted panel at 20 m/s; anchors or ballast are required. Sharp fin edges at ankle and hand height.

### Problems and notes

- The kit cutaway only cuts east-west, which hid the gutter, flaps and fan, so `concept_media.py` builds a north-south cutaway with the kit's own renderer and adds callouts with the same projection.
- The CaCl₂ deliquescence point (about 30 % RH) is quoted without a source; the session's web search budget ran out. Add a source at TRL 3.
- The legacy `cad/src/model.py` placeholder is untouched (TRL 3 work).

### Recommended next step

Review this note and the media, then decide items 1 and 2. If approved, run `/advance-trl3` to replace the estimated isotherms with published or measured data, check the heat and mass balances and the condenser temperature by calculation, and produce the parametric model and drawing sheet.

## Session 2026-09-25: TRL 3

Amish's instruction for this session (2026-09-25): "proceed with all of your recommendations across all batches. Make sure we don't proceed to TRL 4 on any of them." DewDrive now claims TRL 3 (proof of concept on paper). TRL 4 is on hold by Amish's instruction. The main result is unwelcome: the design as drawn does not meet its water targets.

### What was done

- `docs/decisions/0001-trl2-review-decisions.md` (DWD-DDR-001 v0.1): the eight TRL 2 review items with a recommendation recorded as decided by Amish, 2026-09-25 (D1 to D8), and the items that stay open (O1, O2).
- `docs/04-calcs/01-sizing.md` (DWD-CAL-001 v0.1) and `docs/04-calcs/sizing.py`: psychrometrics; a CaCl₂ and silica gel isotherm from the Conde (2004) solution correlation, solubility data and the SaltWiki hydrate transitions; night mass transfer as drawn (laminar flow past the trays) and for a through-flow option; a time-stepped night and day cycle with a lumped bed, Stefan diffusion to the condenser, bed-to-condenser radiation and a finned natural-convection condenser, repeated until the bed water at dawn repeats; stagnation and touch temperatures; salt containment against pore volume; electrical energy; mass from the model volumes; wind overturning and sliding; logging storage; cost. The script imports the model's `PARAMS`, `derived()` and part volumes, reads `bom/bom.csv`, prints every quoted number with a tag [A1] to [K1], and writes `docs/04-calcs/results.csv`. It runs in about 2.5 min.
- `cad/src/model.py`: parametric build123d model (stand in true 30 x 30 x 3 mm angle, walls, glazing, four trays and sorbent bed, condenser plate and 21 fins, gutter and drain, flaps, fan hood, bottle, PV pole, electronics box, sensor shield), exporting `cad/step/dewdrive-assembly.step`, `collector-box.step`, `condenser.step`, `sorbent-trays.step`, `stand.step`, `power-and-logging.step` and matching STL files in `cad/stl/`.
- `cad/src/sheets.py` and `cad/drawings/DWD-DWG-001.svg`, `.pdf`, `.png`: general arrangement at Rev P1, scale 1:20, with overall, box, top-edge and low-edge dimensions computed from the model and a main-dimensions box. The sheet carries "CONCEPT, NOT FOR FABRICATION" and "PRELIMINARY, NOT FOR FABRICATION". The concept sheet stays DWD-DWG-010, so DWG-001 was the next free number.
- `bom/bom.csv` and `bom/bom-notes.md`: all 14 lines priced with a supplier type; total $488 against the new $500 budget (line 1 now includes two ground anchors).
- `cad/src/concept_media.py` now builds the media from `model.py` and takes its key figures and water flow from the calc script; all media in `media/` were regenerated and checked by eye; temporary `media/_views*` folders were deleted.
- DWD-PRB-001, DWD-PRC-001 and DWD-REQ-001 revised to v0.3 (decisions recorded, numbers replaced by DWD-CAL-001, status column from the calc); `README.md` updated to TRL 3 with the new problem line and links; `project.yaml` set to `trl: 3`, `trl_target: 3`, `budget_usd: 500`, the reworded problem line, and the evidence files listed. PDFs are in `docs/pdf/`.

### Requirements (DWD-CAL-001, Table 4)

8 met, 2 not met, 1 at risk, 2 not verifiable at TRL 3.

| ID | Status | Value against target |
| --- | --- | --- |
| R1 | **Not met** | 0.20 L per day as drawn against 0.5 L; about 0.53 L with the proposed through-flow trays |
| R2 | **Not met** | 0.09 L per day at 25 % RH as drawn against 0.25 L; about 0.35 L with through-flow |
| R7 | At risk | At 33 wt % salt the solution fills the pores above 51 % RH; one 90 % RH night fills 46 % of them as drawn, 111 % with through-flow |
| R6 | Not verifiable at TRL 3 | Water quality needs a laboratory test |
| R10 | Not verifiable at TRL 3 | Wind: 49 kg of ballast or two 120 N anchors are needed at 20 m/s; UV life and cycling need supplier data and test |
| R3, R4, R5, R8, R9, R11, R12, R13 | Met | Bed 104 °C at noon; 23.6 Wh per day against 35 Wh, 2.6 days autonomy; condenser 13.1 K above ambient (thin margin); two actions a day; box 30.9 kg; $488; 0.41 MB of logs; glazing 53 °C and fins 48 °C |

Other key numbers: the night air flowing past the trays captures only about 11 % of the vapour driving force (NTU 0.32 over and 0.06 under the trays), so the bed swings by 0.23 kg a night although it could hold 2.03 kg; doubling the fan flow gives only 0.21 L per day. Of the 3.68 kWh the trays absorb, only 0.17 kWh desorbs water, 1.51 kWh is lost through the glazing and 1.96 kWh radiates from the beads through the mesh floors onto the condenser. Solar-to-water efficiency 2.5 % as drawn and 6.5 % with through-flow. Total mass 51.4 kg (TRL 2: 45 kg). Every TRL 2 number in the docs was checked against the script and corrected where it differed (DWD-CAL-001, Table 5).

### Decisions recorded (DWD-DDR-001)

Decided by Amish, 2026-09-25, going with the recommendation: D1 `budget_usd` raised to $500 (set in `project.yaml`; R11 redefined); D2 problem line reworded (applied to `project.yaml` and `README.md`; the pitch had no recommended change and is kept); D3 silica gel with about 33 wt % CaCl₂; D4 single-stage flat box with the condenser as its shaded floor; D5 fan-assisted airflow with a 10 W panel and a 12.8 V LiFePO4 battery; D6 manual flaps; D7 fixed 20° tilt and twin-wall polycarbonate; D8 the design point. DewDrive does not use a SwapCell pack, so the SwapCell interface v0.3 items and the shared-pack pricing rule do not affect it.

### Proposed, awaiting Amish

Status update, 2026-09-25: items 2 to 7 below are now **Decided by Amish, 2026-09-25: go with recommendation** (DWD-DDR-002, D9 to D14; see the session "recommendations accepted" below). Item 1 stays Proposed, awaiting Amish.

Still open from TRL 2 (no recommendation was made):

1. First partner and region for co-design, which also supplies the site climate data (O1). Portfolio rule: partners are picked per area later.

New from TRL 3:

2. **Night airflow through the bed (R1, R2).** Options: (a) seal the tray edges and draw the night air down through the mesh-floored trays (about 0.53 and 0.35 L per day; 0.15 Pa of extra pressure drop; a tray gasket and a baffle, a few dollars); (b) keep the flow past the trays and add bed area with more, thinner trays (less effective: even twice the transfer conductance gives 0.29 L per day); (c) accept the as-drawn yield and relax R1 and R2. Recommendation: (a).
3. **Salt loading (R7).** Lower the CaCl₂ to about 25 wt % (1.0 kg in 3.0 kg of gel): the pores then fill only above about 71 % RH, a 90 % RH night fills 82 % of them with through-flow, and the yield stays about 0.51 L per day. Recommendation: adopt together with item 2. This would amend decision D3.
4. **Humid-night protection (R7).** A drip tray under each sorbent tray, and a logger rule that stops the fan above about 70 % RH. Recommendation: adopt both; the fan rule costs nothing.
5. **Bed-to-condenser radiation.** A perforated low-emissivity aluminium screen under the trays would cut most of the 1.96 kWh a day that the beads radiate onto the condenser, lowering its temperature. Recommendation: evaluate on paper before any build; not needed to meet R5 today.
6. **Wind restraint (R10).** Two auger ground anchors are now in BOM line 1; ballast of about 50 kg is the alternative. Recommendation: confirm anchors as the default.
7. **Budget margin.** The BOM is $12 under the $500 budget. Recommendation: keep `budget_usd` at $500; items 2 to 4 add only a few dollars.

### Safety concerns

- Untreated water: possible bacteria, salt carry-over and aluminium from the condenser. The documents require testing and treatment before drinking.
- Hot surfaces: the bed reaches about 104 °C at noon and about 105 °C dry; the glazing supplier rating must exceed that. Outer glazing about 53 °C, fins about 48 °C.
- Calcium chloride: at the decided 33 wt % loading, a humid spell above 51 % RH can fill the pores and weep a corrosive brine (R7 at risk); items 3 and 4 above address it.
- LiFePO4 battery: BMS, fuse at the battery, shaded mounting.
- Wind: without restraint the unit tips at 20 m/s (overturning ratio 0.77); anchors or about 50 kg of ballast are required.

### Citations

The TRL 2 note flagged the CaCl₂ deliquescence point as unsourced. It is now sourced to [SaltWiki](https://www.saltwiki.net/index.php/Calcium_chloride) (about 30 % RH at 20 °C, and the hydrate transitions at 18.5 % and 9 % RH), with solubility from [Wikipedia](https://en.wikipedia.org/wiki/Calcium_chloride). The Conde (2004) correlation parameters for CaCl₂ solutions (*Int. J. Thermal Sciences* 43, 367 to 382) were entered from the published form but could not be checked against the paper in this session (the one web copy tried was behind a verification page); they reproduce the deliquescence point within 0.04 and should be checked against the paper before TRL 4.

### Existing TRL 4 material

None found. `build-log/README.md` is the empty scaffold and was not extended; `electronics/` and `firmware/` are empty.

### Recommended next step

Review this note and decide items 2 to 4, which decide whether DewDrive can meet its water targets at all. Those decisions can be written into the precis, model and calculation as a paper revision at TRL 3. **TRL 4 is on hold by Amish's instruction** and no TRL 4 work was started. For reference only, TRL 4 would need: measured sorption isotherms and uptake rates of the chosen composite (including the salt loading); a lab test article of one tray with through-flow; a test plan and report (TST, `environment: lab`) covering yield, condenser temperature, salt carry-over and brine containment; a laboratory water test; and build log entries.

## Session 2026-09-25: recommendations accepted

Amish wrote on 2026-09-25: "i accept all your recommendations, go with them across all repos." Every open item with a recommendation is now **Decided by Amish, 2026-09-25: go with recommendation**, recorded in `docs/decisions/0002-recommendations-accepted.md` (DWD-DDR-002 v0.1). TRL stays 3 (`trl: 3`, `trl_target: 3`).

### Decisions applied and what changed

| # | Decision | Before | After |
| --- | --- | --- | --- |
| D9 | Night air drawn down through the sealed, mesh-floored trays | Air past the trays; 0.20 L/day at 40 % RH, 0.09 L at 25 % | Baffle and EPDM tray gasket; inlet flap moved above the trays (800 x 70 to 800 x 40 mm); 0.57 and 0.45 L/day |
| D10 | Salt loading 25 wt % (amends D3) | 1.3 kg CaCl₂ in 2.7 kg gel; pores fill at 51 % RH; bed 8.3 mm | 1.0 kg in 3.0 kg; pores fill at 71 % RH; bed 9.3 mm |
| D11 | Drip tray under each tray and fan stop above 70 % RH | None | New BOM line 15: four black drip screens (two staggered layers of channels, sumps 0.58 L in all); fan rule in DWD-PRC-001. R7 restated to the tray and drip-screen assembly |
| D12 | Evaluate a low-emissivity screen on paper | Not evaluated | Done: 0.82 L/day but 166 °C dry-bed stagnation; not adopted (see O4) |
| D13 | Ground anchors as the default wind restraint | Anchors or ballast | Two anchors of 114 N default; 46 kg ballast the alternative |
| D14 | Keep `budget_usd` at $500 | $500; BOM $488 | $500 unchanged; BOM $515 |

Other changes: `cad/src/model.py` (baffle, drip screens, raised inlet, bed depth), STEP and STL re-exported; drawing DWD-DWG-001 re-run at Rev P2; `docs/04-calcs/sizing.py` and DWD-CAL-001 v0.2 now model the decided design (results.csv regenerated); `bom/bom.csv` and `bom-notes.md`; DWD-PRB-001, DWD-PRC-001 and DWD-REQ-001 to v0.4; DWD-DDR-001 to v0.2 (O2 marked decided); all media regenerated from the model and checked by eye (`_views` folders removed); PDFs re-rendered; README given the concept rationale, burning platform, where-used and inspiration sections, with the concept figures updated.

Other key numbers: bed 112 °C at noon (was 104 °C), stagnation 122 °C (was 105 °C), condenser rise 12.1 K (was 13.1 K), solar-to-water efficiency 7.1 % (was 2.5 %), mass 53.9 kg and box 33.4 kg (were 51.4 and 30.9 kg), water cost $0.49 per litre over 5 years (was $1.34). If grain kinetics cut the night NTU to 1, the yield is still 0.53 L/day (C9).

### Requirement status (DWD-CAL-001 v0.2, Table 4)

10 met, 1 not met, 2 not verifiable at TRL 3.

| ID | Status | Value against target |
| --- | --- | --- |
| R11 | **Not met** | $515 against $500 |
| R6 | Not verifiable at TRL 3 | Water quality needs a laboratory test |
| R10 | Not verifiable at TRL 3 | Two 114 N anchors or 46 kg ballast at 20 m/s; UV and cycling need supplier data and test |
| R1, R2 | Met | 0.57 L/day against 0.5; 0.45 L/day against 0.25 |
| R7 | Met on paper | Pores 43 % full after one 90 % RH night; 50 % after three with the fan rule (63 % without); sumps 0.58 L |
| R3, R4, R5, R8, R9, R12, R13 | Met | Bed 112 °C; 23.6 Wh/day against 35; 12.1 K; two actions; box 33.4 kg; 0.41 MB; glazing 57 °C, fins 47 °C |

### Still awaiting Amish

1. **O1.** First partner and region for co-design (no recommendation made).
2. **O3, budget (new). Decided by Amish, 2026-09-26: budget top-up to $520 (DWD-DDR-002 v0.2, D15).** BOM $515 against $500. Options: (a) raise `budget_usd` to $520; (b) cut the drip screens to drip gutters under the low edge of each tray (weaker protection); (c) evaluate a lighter condenser on paper, since the black screens cut its peak load from 333 W to 299 W. Recommendation: (c) first, then (a) if it does not close the gap.
3. **O4, low-emissivity screen (new).** 0.82 L/day but a 166 °C dry-bed stagnation. Recommendation: evaluate a stagnation vent or higher-rated glazing on paper at TRL 3.
4. **O5, glazing rating (new).** Dry-bed stagnation is 122 °C, near the usual 120 °C service rating of twin-wall polycarbonate. Recommendation: specify a sheet rated 130 °C or more, or confirm from supplier data that the inner skin stays inside the rating.

### Cross-repo actions

None. DewDrive has its own battery and uses no shared interface, so no decision here needs another repo to change.

### Safety concerns

- The bed now reaches about 112 °C at noon and 122 °C dry (was 104 and 105 °C); the glazing rating must be confirmed (O5). Low-emissivity screens are not to be fitted.
- Brine in the drip-screen sumps is corrosive; emptying them needs gloves and eye protection, and they must be kept apart from the water path.
- Untreated water, the LiFePO4 battery and wind loads are as before; the documents keep all safety sections.

### TRL 4

**TRL 4 remains on hold by Amish's instruction.** No build, test, purchase, PCB or firmware beyond a sketch was started. The fan rule is a design rule only; measured isotherms, a through-flow tray test article, a drip-screen chamber test and a water test remain for TRL 4.

## Session 2026-09-26: sources strengthened

Every link in the README's rationale, burning platform, use tables and inspiration was fetched and checked against its claim.

| Where | Old source | New source |
| --- | --- | --- |
| README, What sparked the idea (Telkes solar still) | Encyclopedia.com with USPTO | USPTO, "A solar life", and US Patent 3,415,719 (Google Patents). The text now says what these support: the still was ordered by the US government but not delivered or used during the war, and later entered military emergency kits; the claim that it supplied torpedoed sailors on life rafts is removed |
| README, Navajo Nation row | Native News Online alone | US Senate Committee on Indian Affairs hearing page (September 27, 2023, Speaker Curley's testimony), with Native News Online kept for the 30 % figure |
| README, Kenya row (was "Northern Kenya and the Horn of Africa", uncited) | none | UNICEF Kenya; row rewritten to what UNICEF states: access is lowest in the arid and semi-arid land counties |
| README, Rajasthan row (uncited) | none | Al Jazeera (2015): Thar Desert villages, water scarce up to 11 months a year, walks of up to 4 km, taanka rainwater storage |
| README, Atacama row (uncited) | none | Carter et al., *Frontiers in Environmental Science* (2025), doi:10.3389/fenvs.2025.1537058: Alto Hospicio, 1.6 % of informal settlements connected to the network, 75.4 % supplied by truck, fog collection assessed |

`INSPIRATIONS.md` line for DewDrive updated to the new sources (same event). `docs/01-problem.md` did not cite the replaced sources.

### Budget top-up

Budget top-up to $520: decided by Amish, 2026-09-26 ("I am ok with the budget top ups"). This closes O3.

- `project.yaml`: `budget_usd` 500 to 520.
- DWD-REQ-001 v0.5: R11 target $520 or less; status Met at $515 (11 of 13 met, R6 and R10 not verifiable at TRL 3).
- DWD-CAL-001 v0.3: `sizing.py` budget updated and re-run; only R11 changed in `results.csv` (now met).
- DWD-DDR-002 v0.2: new row D15; O3 marked decided.
- DWD-PRB-001 v0.5 and DWD-PRC-001 v0.5: budget text updated; `bom/bom-notes.md` and README (budget line, parts cost row) updated; concept blueprint label changed to "budget $520" and media regenerated.

## Session 2026-09-26: product appearance model and photoreal renders

Amish chose this repo for the first batch of product renders on 2026-09-26.

### What was done

- `cad/src/product_model.py` (new): a product appearance model for photoreal renders. `product_parts()` returns each part with its shape, colour, material, BOM line, group and explode offset; `TITLE` and `RENDER_VIEWS` (hero, exploded and a back-right detail view) drive the renderer. It imports `PARAMS`, `derived()`, `tray_centres()`, `world()` and `build_parts()` from `cad/src/model.py`, and reuses the stand, drip screens, condenser and sorbent bed unchanged. It adds:
  - painted plywood walls with filleted corners and a shadow-gap parting line, and a teal nameplate on the south wall;
  - an aluminium lid edge frame holding a clear twin-wall polycarbonate pane (ribs down the slope), so the black trays and the sorbent beds show through; three lid hinges on the north edge and a pull handle on the south edge;
  - wire lift bails on the four trays and the sealing baffle and rails as a separate aluminium part;
  - the gutter, a silicone drain tube with a wall grommet, and a 10 L jerrycan with moulded side ribs, a carry handle, a knurled teal cap and a label;
  - the south inlet flap with its EPDM seal, a five-knuckle hinge and two over-centre latches; the louvred fan hood (open underneath) with a fan guard, and the north outlet flap with its hinge;
  - bolts on the stand foot pads, two auger ground anchors with webbing tie straps and ratchets;
  - a framed PV panel with cells, busbars and a junction box, pole clamps on the leg;
  - an IP65 electronics box with a lid, lid screws, a label, cable glands, a lit green status light and a bracket to the leg, a sheathed cable up the leg, and a stacked-plate radiation shield with a domed cap;
  - context: a compact patch of compacted gravel ground, not in the BOM.
- `README.md`: hero image line now points to `media/render-hero.png`, and the links line starts with the exploded render. The render files are produced separately by the render pipeline.
- Self-check previews (matplotlib, clear parts omitted) were used to set the views; they are scratch files and not in the repo.

### Where the appearance model differs from model.py

Every main dimension, the tilt, the heights and all interfaces are as `model.py`. The differences are cosmetic; each is **Proposed, awaiting Amish**:

1. **Ground anchor position and tie-down.** `model.py` does not model the two auger anchors that BOM line 1 includes. The appearance model places them 190 mm outboard of the two south legs, tied to the legs with webbing straps. Recommendation: accept for the renders; the anchor position and tie-down detail belong to the wind-load check at TRL 4 (DWD-CAL-001, H2 to H4).
2. **Electronics box orientation.** The appearance model puts the lid, label and status light on the north face, outward from the stand, so they can be reached without reaching under the box. Recommendation: accept.
3. **Radiation shield.** Drawn as seven stacked plates with a domed cap on a post; its top is about 30 mm higher than the 110 mm cylinder in `model.py`, and the top plate is 96 mm across instead of 90 mm. Recommendation: accept; the shield is a bought part and its size depends on the product chosen.
4. **Jerrycan handle and neck.** The moulded carry handle adds about 48 mm above the can top, beside the cap at the `model.py` position. Recommendation: accept; the drain tube end and cap position are unchanged.
5. **Rounded corners and lid frame.** The box corners are filleted (radius 14 mm) and the glazing sits in a 22 mm aluminium edge frame within the same 1,100 x 1,000 mm outline, as BOM line 3 describes. Recommendation: accept.

### TRL

This is an appearance model only: no tolerances, no fabrication detail, no build or test work. `trl` stays 3, and **TRL 4 remains on hold** by Amish's instruction.

## Session 2026-09-27: kit 1.5.0 and image quality

- Kit 1.5.0 synced: STANDARDS v1.5 (sections 12 to 15: product renders, storefront images and image quality, public release, authorship and signing), `.kit/cards.py`, `.kit/image_qc.py`, `.kit/release_gate.py`, issue templates, and the `/render-product` and `/release` commands. `CLAUDE.md` now matches `.kit/CLAUDE.md`.
- Every `media/render-*.png` recaptioned from its original render with the new layout: the title, concept label and repository sit in a band above the render and the view note in a band below it, each line wrapped to the image width, so no text overlaps other text or the render or runs off the image. `media/card.png` and `media/social-preview.png` regenerated with the same rules.
- `python .kit/image_qc.py` and `python .kit/release_gate.py` pass. trl stays 3.

## Session 2026-10-01: kit 1.7.0, constructable design and prototype build plan

Done under the build plan rollout (kit 1.7.0) and Amish's instruction of 2026-09-30 to make the design physically buildable while drawing the build plan. TRL stays 3; nothing was built, bought or tested.

### What was done

- Kit 1.7.0 installed (`.kit/`, `.claude/commands/`); `CLAUDE.md` replaced by `.kit/CLAUDE.md`.
- `cad/src/model.py` rewritten from a massing model to a constructable one: every made or bought piece is its own component with its material, and `python cad/src/model.py --check` runs 91 constructability checks (contacts, overlaps, clearances); all 91 pass. `build_parts()` keeps the old BOM groups, plus a new group for line 16.
- New decision record `docs/decisions/0003-design-for-construction.md` (DWD-DDR-003, draft, open for Amish's review).
- New build plan `docs/05-build-plan.md` (DWD-BLD-001) with pictures from `cad/src/build_plan_media.py`: an overview, 22 making sketches (`cad/drawings/DWD-DWG-101` to `122`), 14 joint close-ups, 19 assembly steps, a plate hole layout and a wiring diagram, all in `docs/05-build-plan/`.
- New design decisions register `docs/06-design-decisions.md` (DWD-DEC-001).
- `bom/bom.csv`: lines repriced and line 16 (tray deck and wall ledges) added; $620 in all.
- `docs/04-calcs/sizing.py` re-run on the new model (DWD-CAL-001 v0.4): mass by component and material, outlet slot in the fan duty, new leg span in the wind check.
- DWD-REQ-001 v0.6, DWD-PRC-001 v0.6, README (links line, "Building the prototype", key numbers), `project.yaml` (`design_state: constructable`, new evidence) updated.
- STEP and STL re-exported, general arrangement DWD-DWG-001 at Rev P4, concept media regenerated from the new model; PDFs of the changed documents re-rendered.

### Design changes made for construction (DWD-DDR-003)

1. Condenser plate under the walls, closing the box; walls start 5 mm higher and are 133 mm tall so every height and gap in the calculation is kept (the concept plate overlapped the walls by 240 cm³).
2. Walls as battened sandwich panels, screwed at the corners, with framed openings and threaded inserts for the stand.
3. A lift-out tray deck (20 x 5 mm flat bar frame, baffle riveted on top, EPDM edge seal) on two wall ledges, in place of a loose 1 mm baffle on unfixed rails.
4. Drip screens framed and hung from the deck bars by their sump and end plate (they floated 7 mm below the trays); sumps moved under the channel ends.
5. Fins with a 10 mm folded foot, bonded and riveted with closed-end rivets.
6. A folded L gutter in the low corner and a bulkhead drain fitting down through the floor between two fins (the concept gutter could not take water in).
7. One outlet: a slot under the deck into a fan hood, with the outlet flap over the fan. The concept's separate outlet flap would have let the fan draw air past the beds, and a 120 mm fan did not fit under the trays.
8. Inlet opening lowered 20 mm (same 800 x 40 mm, still above the deck) so the wall keeps a solid top edge.
9. Lid sheet in an aluminium U-channel frame with hinges, latches and a seal.
10. Stand redesigned: rails under the box edges bolted into the wall inserts, legs bolted to the rails, side braces, cross members, a south diagonal, foot plates with cleats (the concept stand ran through the box).
11. PV pole as a square tube on spacers on the north-east leg, 6 mm clear of the box (the concept pole passed through the box).
12. Electronics box and sensor shield on a backing plate on the north-west leg.
13. Trays as folded 1 mm pans with a perforated floor under the mesh.

### Key results (DWD-CAL-001 v0.4)

- Water, heat, salt and electrical results unchanged: 0.57 and 0.45 L per day, bed 112 °C at noon, condenser rise 12.1 K, pores fill at 71 % RH.
- **R11 over the value-engineering target:** parts an estimated $620 against a $520 target ($100 over).
- **R9 not met as written:** full box 35.2 kg against 35 kg; 23.4 kg with the trays, sorbent, deck and screens lifted out. Total 60.2 kg.
- Wind: two anchors of 98 N, or 40 kg of ballast. Fan duty about 3.3 Pa.
- Requirement count: 9 met, 1 not met (R9), 1 over its value-engineering target (R11), 2 not verifiable at TRL 3 (R6, R10).

### Proposed, awaiting Amish

All open decisions are in the design decisions register (`docs/06-design-decisions.md`): review of DDR-003; restating R9 for a lift with the trays and deck out; the glazing rating (O5); the low-emissivity screen (O4); the co-design partner (O1); and the appearance model deviations.

### Stale on Amish's Mac

The photoreal renders (`media/render-hero.png`, `media/render-exploded.png`, `media/render-detail.png`), `media/card.png` and `media/social-preview.png`, and the appearance model `cad/src/product_model.py`, still show the concept stand, lid frame, outlet flap and PV pole; they need regenerating after the appearance model is brought into line with `model.py`.

### Safety concerns

- Sorbent preparation (calcium chloride dissolving hot, corrosive brine) now has written steps and stops (build plan S1, S2, S7).
- The glazing rating (122 °C stagnation) must be confirmed before the lid is first closed in sun (S3).
- Mass rose by 6 kg; the build plan lifts the box onto the stand with the trays and deck out, two people, after the anchors are in (S4).

### Recommended next step

Amish to review DDR-003 and decide the R9 item in the register; its Value engineering section has the cost drivers. TRL 4 remains on hold; when released, the build plan is ready to build from.

## Session 2026-10-02: open decisions decided

On 2026-10-02 Amish approved every recommendation written for the open decisions: "i approve your recommendations for all 555 open decisions." trl stays 3; nothing was built or tested.

### Decisions recorded

6 decisions recorded in the design decisions register (DWD-DEC-001, Decisions made, dated 2026-10-02): DWD-DDR-003 accepted as made (1); R9 restated for a lift with the trays and deck taken out, with an empty-before-lifting label (2); glazing rated 130 °C or more (3); a short paper study of a passive stagnation vent, else drop the low-emissivity screens (4); first partner type and region (5), the first candidate to approach and not an agreed partner; appearance deviations accepted and renders to be updated (6).

### Documents changed

- `docs/06-design-decisions.md` (DWD-DEC-001 v0.3): all 6 open items moved to Decisions made; Open decisions now reads "None"; item 2 of "To confirm when parts are bought" updated for the glazing rating.
- `docs/decisions/0003-design-for-construction.md` (DWD-DDR-003 v0.3): status line records acceptance of Tables 1 and 2 and of A2; status stays Draft.
- `docs/decisions/0002-recommendations-accepted.md` (DWD-DDR-002 v0.3): O1, O4 and O5 recorded as decided.
- `docs/decisions/0001-trl2-review-decisions.md` (DWD-DDR-001 v0.3): O1 recorded as decided.
- `docs/01-problem.md` (DWD-PRB-001 v0.7): partner and region named as the first candidate type to approach.
- `docs/03-requirements.md` (DWD-REQ-001 v0.8): R9 restated and met; count of requirements met updated.
- `docs/04-calcs/01-sizing.md` (DWD-CAL-001 v0.6): R9 row and counts for the restated R9; glazing rating decision noted in section D; no computed number changed.
- `docs/02-concept.md` (DWD-PRC-001 v0.8): glazing rating, low-emissivity study, R9, lifting rule and partner from the 2026-10-02 decisions.
- `docs/05-build-plan.md` (DWD-BLD-001 v0.3): glazing rated 130 °C or more (sections 3.9 and 3.19, stop S3); lifting label in step 16 and stop S4.
- `bom/bom-notes.md`: glazing rating and lifting label noted; BOM changes are follow-ups.
- `README.md`: the portability and cost sentence of "Building the prototype".
- PDFs re-rendered with `python .kit/render.py`; superseded versions removed.

No CAD model, BOM quantity or price, or picture was changed. Requirement status: R9 is now met as restated, so 10 met, 1 over its value-engineering target (R11, $620 against $520), 2 not verifiable at TRL 3 (R6, R10).

### Follow-up actions to carry approved decisions into the design

1. Decision 2 (bom): Add an "Empty before lifting" label to the BOM (a line or within line 3 or the box line) and show it in the step 16 picture.
2. Decision 2 (calcs): Re-run `docs/04-calcs/sizing.py` with R9 as restated so `results.csv` and the counts [K1] report R9 met.
3. Decision 3 (bom): Change the BOM line 3 specification to twin-wall polycarbonate rated 130 °C or more (price to be checked; a higher-rated sheet may cost more).
4. Decision 4 (calcs): Write the short paper study of a passive stagnation vent in DWD-CAL-001; if it cannot hold a dry bed near 122 °C at a modest cost, record that the low-emissivity screens are dropped.
5. Decision 6 (pictures): Update the appearance model `cad/src/product_model.py` to the constructable design (stand, lid, no outlet flap) with the five accepted deviations, and regenerate the photoreal renders, `media/card.png` and `media/social-preview.png` on Amish's Mac.

### Points found in the review

- The constructable design is USD 620 against the USD 520 value-engineering target (19 % over), and the savings listed still leave it over.
- Renders still show the concept stand, lid and the outlet flap that P7 removed.

### Safety

The glazing must now be rated 130 °C or more, against a dry-bed stagnation near 122 °C; a 120 °C sheet is allowed only with supplier data and a measured inner-skin temperature. The box must be emptied of its trays and deck before any lift. Low-emissivity screens stay out of the prototype.

### Recommended next step

Carry out the follow-up actions above, starting with the BOM line 3 glazing specification and the stagnation vent study. TRL 4 remains on hold by Amish's instruction.

## Approved follow-ups carried out (2026-10-02)

Amish approved all follow-up actions from the 2026-10-02 sign-off. trl stays 3; no build or test work was done.

### Follow-ups

1. Decision 2 (BOM and picture): done. The "Empty before lifting" label is bill of materials line 14 (about $2, estimate), modelled as a 0.5 mm plate on the east wall in `cad/src/model.py` (two new constructability checks; 93 checks in all, all passing), and drawn yellow in the step 16 picture. The step 16 text in the build plan now says where it goes.
2. Decision 2 (calculations): done. `docs/04-calcs/sizing.py` now tests R9 on the box lifted with the trays and deck out (23.4 kg, met); it was re-run and `results.csv` and the counts [K1] agree: 10 met, 1 not met (R11), 2 not verifiable at TRL 3.
3. Decision 3 (BOM): done. Line 3 now specifies twin-wall polycarbonate rated 130 °C or more, priced at about $48 per square metre (an estimate, about 50 % above a standard sheet, no supplier quote), so line 3 rises from $65 to $82. A quote is still needed.
4. Decision 4 (calculations): done. The study is in DWD-CAL-001 section D (D4, D5): about 117 cm² of stack-effect vent would hold a low-emissivity dry bed at 122 °C, but it would have to stay shut in normal operation (bed 130 to 149 °C), so it needs a thermostat and is not a passive, modest-cost fix. The low-emissivity screens are dropped; the black screens stay (recorded in DWD-DEC-001 v0.4).
5. Decision 6 (appearance model and pictures): done in part. `cad/src/product_model.py` now takes the lid frame and hinges, latches, deck and ledges, gutter and drain, inlet flap hardware, outlet flap, stand, PV pole and bracket, backing plate and bolts from the model, moves the electronics box and shield to the backing plate, and adds the label. Render scenes were exported to `/home/claude/renders/dewdrive` (hero, exploded, detail, and the jobs file). Not done: the photoreal renders, `media/card.png` and `media/social-preview.png`, which are made on Amish's Mac.

### Key results

- Cost: USD 639 against the USD 520 value-engineering target (USD 119 over); USD 620 before these follow-ups (USD 17 for the 130 °C glazing sheet, USD 2 for the label). `budget_usd` is unchanged.
- Mass: 60.2 kg total, box 35.2 kg, 23.4 kg lifted with the trays and deck out; unchanged.
- Requirement status changes: R9 now reads met in `results.csv` (it was not met under the first wording; the written status already read met after the restatement). R11 stays over its target, by USD 119 (was USD 100).

### Documents changed

- `docs/04-calcs/01-sizing.md` (DWD-CAL-001 v0.7), `docs/03-requirements.md` (DWD-REQ-001 v0.9), `docs/02-concept.md` (DWD-PRC-001 v0.9), `docs/05-build-plan.md` (DWD-BLD-001 v0.4), `docs/06-design-decisions.md` (DWD-DEC-001 v0.4), `docs/decisions/0003-design-for-construction.md` (DWD-DDR-003 v0.4), `bom/bom.csv`, `bom/bom-notes.md`, `README.md`.
- `cad/src/model.py` (label), STEP and STL re-exported; `cad/src/sheets.py` and `cad/drawings/DWD-DWG-001` at Rev P5; concept media regenerated; build step 16 picture regenerated; `docs/04-calcs/results.csv` regenerated.
- PDFs re-rendered with `python3 .kit/render.py`.

### Cross-repo actions

None.

## 2026-10-02: photoreal renders redone on the constructable design

Rendered with Blender Cycles on Amish's Mac from the updated appearance model; captioned with `.kit/photo_caption.py`; `media/card.png` and `media/social-preview.png` regenerated with `.kit/cards.py`. Views: hero, exploded, detail. image_qc passes. Appearance deviations are those logged above as proposed, awaiting Amish.

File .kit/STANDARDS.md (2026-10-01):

---
doc_id: OHP-STD-001
title: Documentation and drawing standard
project: Open Hardware Portfolio
doc_type: Standard
version: "1.7"
status: Released
date: 2026-09-30
author: Amish Chadha
license: CC-BY-SA-4.0
revisions:
  - version: "1.0"
    date: 2026-09-24
    author: Amish Chadha
    change: First release of the standard
  - version: "1.1"
    date: 2026-09-24
    author: Amish Chadha
    change: Adopt Technology Readiness Levels (section 9) for project maturity
  - version: "1.2"
    date: 2026-09-24
    author: Amish Chadha
    change: Portfolio phase cap (section 10), concept media standard (section 11), CLAUDE.md guardrails
  - version: "1.3"
    date: 2026-09-24
    author: Amish Chadha
    change: Scale figure, interactive 3D viewer and flow diagrams added to concept media; session slash commands
  - version: "1.4"
    date: 2026-09-26
    author: Amish Chadha
    change: Every sheet and render names the project and its GitHub repository; overall dimensions, ISO centre lines and 300 dpi PNG on sheets; titles name the device and view labels state the viewing direction; optional photoreal renders with Blender
  - version: "1.5"
    date: 2026-09-27
    author: Amish Chadha
    change: Product renders (section 12), storefront images and image quality check (section 13), public release and release gate (section 14), authorship, citation and commit signing (section 15)
  - version: "1.6"
    date: 2026-09-29
    author: Amish Chadha
    change: Licensing metadata with REUSE (section 16), Zenodo DOI and Software Heritage archiving (section 17), release gate checks REUSE and a single CITATION.cff license, archive.py
  - version: "1.7"
    date: 2026-09-30
    author: Amish Chadha
    change: Concept and constructable design states; design decisions register (DEC) kept apart from the build plan; prototype build plan (BLD, section 18) with pictures by component is required TRL 3 evidence; every repo targets TRL 3 during the populate phase; build_views.py; /to-trl3 and /build-plan commands
---

# Documentation and drawing standard

Every project in the portfolio uses this standard, so that each precis, write-up and sketch looks the same and carries its own version history. The standard ships as a kit in each repo's `.kit/` folder. The kit version is in `.kit/KIT_VERSION`.

## 1. Document types and IDs

Every controlled document has a unique ID in the form `PRJ-TYP-NNN`.

- `PRJ` is the three-letter project code listed in section 7.
- `TYP` is the document type code from the table below.
- `NNN` is a sequence number within that project and type, starting at 001.

| Code | Type | Typical file |
| --- | --- | --- |
| PRC | Design precis | `docs/02-concept.md` |
| PRB | Problem statement | `docs/01-problem.md` |
| REQ | Requirements | `docs/03-requirements.md` |
| CAL | Calculation or sizing note | `docs/04-calcs/*.md` |
| DDR | Design decision record | `docs/decisions/*.md` |
| BOM | Bill of materials | `bom/bom.csv` |
| DWG | Drawing or sketch sheet | `cad/drawings/*.svg` |
| BLD | Prototype build plan (section 18) | `docs/05-build-plan.md` |
| DEC | Design decisions register (section 18) | `docs/06-design-decisions.md` |
| TST | Test plan or test report (front matter adds `environment: lab` or `relevant`) | `docs/05-tests/*.md` |

Example: `TBK-PRC-001` is the ThermaBrick design precis.

## 2. Revision scheme

| Artifact | While in draft | When released | Change after release |
| --- | --- | --- | --- |
| Documents | 0.1, 0.2, 0.3 ... | 1.0 | 1.1 for minor edits, 2.0 for a design change |
| Drawings | Rev P1, P2 ... (preliminary) | Rev A | Rev B, C ... |

- Every change to a controlled document adds a row to its revision history before the commit.
- The `version` field in front matter always equals the newest row in `revisions`. The renderer rejects a document where they differ.
- Status is one of `Draft`, `In review`, `Released` or `Superseded`. Draft and In review documents print with a status band on every page.
- Every release is tagged in Git as `<doc_id>/v<version>`, for example `TBK-PRC-001/v1.0`. Drawings are tagged `TBK-DWG-001/revA`.
- Git history is the full audit trail. The in-document revision table is the human-readable summary.

## 3. Document front matter

Every Markdown document under version control starts with this block:

```yaml
---
doc_id: TBK-PRC-001
title: ThermaBrick design precis
project: ThermaBrick
doc_type: Precis
version: "0.1"
status: Draft
date: 2026-09-24
author: Amish Chadha
license: CERN-OHL-S-2.0
revisions:
  - version: "0.1"
    date: 2026-09-24
    author: Amish Chadha
    change: Initial draft
---
```

Quote version numbers so YAML keeps `1.0` as text instead of turning it into a number. List revisions newest last.

## 4. Writing style

- Chicago Manual of Style.
- No em dashes. Restructure the sentence instead.
- Lead each section with its conclusion, then support it.
- SI units throughout, in the form `12 kW`, `450 °C`, `3.2 m`. Imperial values may follow in parentheses.
- Number every figure and table ("Figure 2", "Table 1") and give each a caption.
- State every assumption in the calculation that depends on it.
- Put safety notes in a blockquote starting with **Safety:**.

## 5. Visual identity

| Element | Specification |
| --- | --- |
| Typeface | IBM Plex Sans for text, IBM Plex Mono for code and values (SIL Open Font License, bundled in `.kit/fonts`) |
| Ink | `#111827` |
| Secondary text | `#4B5563` |
| Rules and grid | `#D1D5DB` |
| Accent (one only) | `#0F766E` teal |
| Document page | US Letter, 20 mm margins |
| Drawing sheet | ANSI B landscape (431.8 x 279.4 mm) |
| Footer | Document ID, version, status, license and designmolecule.com on every page |

## 6. Drawing and sketch conventions

- Units are millimeters unless the title block says otherwise.
- Third-angle projection, marked with the symbol in the title block.
- Line weights: visible outlines 0.5 mm, hidden lines 0.25 mm dashed, center lines 0.18 mm chain.
- The title block contains the project, title, drawing number, revision, scale, units, projection, sheet, author, date, material or notes, and license.
- Every sheet and every render names the project and its GitHub repository (from `repo:` in `project.yaml`), at the top of the sheet and in the title block, so a printed or forwarded sheet is never anonymous.
- The drawing title names the device, not only the drawing type (for example "Handheld near-infrared resin scanner: general arrangement").
- Every view label states its scale and viewing direction (for example "Scale 1:1; side elevation looking along +Y"), and every isometric or render states where it is seen from.
- Orthographic views generated with `add_ortho` carry overall dimensions (length and depth on the top view, height on the front view) and ISO 128 centre lines on cylinders; hidden lines are dashed. Tolerances are not shown before TRL 4.
- Sheets are exported as SVG, PDF and a 300 dpi PNG.
- The revision table in the top right of the sheet lists every revision.
- Concept sketches use the same sheet and title block and carry the label "CONCEPT, NOT FOR FABRICATION".
- Geometry comes from `cad/src/*.py` (build123d). Sheets are generated by `.kit/drawing.py` and never edited by hand.

## 7. Project codes

| Code | Project | Code | Project | Code | Project |
| --- | --- | --- | --- | --- | --- |
| TBK | ThermaBrick | PCF | PicoFlow | HLT | HelioLite |
| CCB | CharCube | DRN | DustRunner | TRT | TremorTrace |
| STC | StepCue | FXH | FlexHand | CPD | ColdPod |
| SCL | SunClave | STR | SteamRoot | GGD | GrainGuard |
| SDL | SeedLine | ZBX | ZeerBox | RMS | RootMesh |
| DWD | DewDrive | SSK | StillStack | PPR | PotPress |
| WWT | WaterWatch | LMF | LumaFlow | FCL | FieldCell |
| CNP | ConePro | CVC | CulvertCrawl | EGD | EmberGuard |
| SNF | SnapFrame | CGM | CargoMule | SCM | StepClimber |
| SWC | SwapCell | PLP | PalletPilot | FTK | FlatTrike |
| WWK | WaterWalker | GRR | GrowRider | SSP | SunSpoke |
| SGN | StepGen | PBX | PowerBox | WML | WasteWise-ml |
| WSC | WasteWise Scan | RFE | ReflowEconomy | | |
| OHP | Portfolio-wide | | | | |

## 8. Build and publish

- `python .kit/render.py` checks every controlled document and renders it to `docs/pdf/<doc_id>_v<version>.pdf`.
- `python .kit/drawing.py` (called from each project's `cad/src/sheets.py`) builds drawing sheets as SVG and PDF in `cad/drawings/`.
- The GitHub Action in `.github/workflows/docs.yml` runs the checks on every push and attaches PDFs to a GitHub Release whenever a release tag is pushed.
- Public releases follow section 14: `python .kit/release_gate.py` must pass, and the release tag is `v0.<TRL>.0` (for example `v0.3.0` at TRL 3).

## 9. Technology Readiness Level (TRL)

Each project states its maturity as a Technology Readiness Level on the NASA and US DOE 1 to 9 scale. The TRL rates this specific design, not the underlying technology. A sand battery is commercial elsewhere, but a new sand battery design starts at TRL 2 until evidence shows otherwise.

| TRL | Definition | Evidence the repo must contain |
| --- | --- | --- |
| 1 | Basic principles observed | Problem statement (PRB) |
| 2 | Technology concept formulated | Draft precis (PRC) and requirements (REQ) |
| 3 | Analytical or experimental proof of concept | Calculation note (CAL), working build123d model with STEP export, drawing sheet (DWG), priced BOM with every unit cost filled in, prototype build plan (BLD) with pictures, `design_state: constructable` |
| 4 | Components validated in the lab | Test report (TST) with `environment: lab`, build log entries |
| 5 | Validated in a relevant environment | Test report (TST) with `environment: relevant` |
| 6 | System prototype demonstrated in a relevant environment | Precis at version 1.0 or later with status Released, a drawing at a lettered revision (Rev A or later), and a system-level TST with `environment: relevant` |
| 7 to 9 | Operational demonstration through proven in service | Beyond portfolio scope; claim only with a named deployment partner and evidence |

Rules:

- `project.yaml` records `trl` (current level), `trl_target` (the level the current effort aims for) and `trl_evidence` (the files that support the claim).
- `python .kit/render.py --check` fails if the evidence for the claimed TRL is missing. CI runs this check on every push.
- Documentation alone cannot go past TRL 3. TRL 4 and above require hardware and a test report.
- TRL and visibility are independent. A repo can be public at TRL 3 as a documented design ready to build.
- A change of TRL is recorded in the build log with the date and the evidence that justified it.

## 10. Portfolio phase and TRL cap

`.kit/PHASE.yaml` sets the current phase. During the **populate** phase every repo is capped at **TRL 3**: `trl` and `trl_target` may not exceed 3, and the check fails if they do. Every repo targets the cap: `trl_target` must equal 3, so a new repo is taken all the way to TRL 3 (scaffold, populate and advance, see `/to-trl3`). Work that belongs to TRL 4 or later (building or testing hardware, test articles, test plans and reports, build-log entries, purchasing lists, PCB layouts) must not be started. The prototype build plan (BLD, section 18) is TRL 3 paper work and is required. Where it already exists it is kept, flagged in the check output, and not extended. Only Amish changes `PHASE.yaml`.

Every repo carries a `CLAUDE.md` with the working rules for AI sessions: the TRL cap, decision rights (nothing is recorded as decided unless Amish decided it), one step per session, and a mandatory `docs/REVIEW.md` before stopping.

## 11. Concept media

Every repo at TRL 2 or above explains its idea visually. Media are generated from a build123d massing model with `.kit/concept.py`, never drawn by hand, so they stay in step with the design.

| File | Required | Purpose |
| --- | --- | --- |
| `media/hero.png` | TRL 2+ | Shaded isometric render with a 1.75 m person for scale; the website card image |
| `media/concept-blueprint.png` and `.pdf` | TRL 2+ | Blueprint concept sheet: orthographic and isometric views, scale, key figures, title block |
| `media/model.glb` and `media/viewer.html` | TRL 2+ | Interactive 3D viewer (glTF plus model-viewer) for the website |
| `media/cutaway.png` | When the inside matters | Section view showing internal parts |
| `media/exploded.png` | Recommended | Exploded view with numbered callouts matching the BOM |
| `media/flow.png` | When energy or material moves | System, energy or material flow diagram with losses |

Session commands in `.claude/commands/` (`/populate`, `/advance-trl3`, `/rein-in`, `/refresh-media`) carry the standard prompts, so every Claude Code session starts from the same instructions.

At TRL 2 a massing model is enough: correct overall proportions and main components. All concept media carry "CONCEPT, NOT FOR FABRICATION". The check warns when required media are missing at TRL 2 and fails at TRL 3.

## 12. Product renders

Every repo at TRL 3 shows the product as it would look, not only as a massing model.

- `cad/src/product_model.py` is the appearance model. It defines `product_parts()` (named parts with a shape and a material), `TITLE` ("Name: what it is") and `RENDER_VIEWS`. It is for renders only: every main dimension comes from `cad/src/model.py`, never typed in again.
- Where the appearance model departs from `model.py` (a chamfer, a label, a fastener drawn for realism), record the deviation in `docs/REVIEW.md` as "Proposed, awaiting Amish".
- Scale comes from context, not from a floating figure: a hand or forearm for handheld objects, and the posed mannequin (`mannequin()` in `.kit/context_parts.py`: stand, walk, push, ride, sit, reach) for anything a person uses at body scale.
- Renders are made with `.kit/export_views.py` (one scene per view) and `.kit/photoreal.py` (Blender Cycles), then captioned with `.kit/photo_caption.py`. Files are `media/render-<view>.png`; `media/render-hero.png` is required.
- Every caption names the project, the repository and the viewing direction, and carries "CONCEPT, NOT FOR FABRICATION".
- Captions never sit on the render. `.kit/photo_caption.py` adds a header band (title, concept label, repository) above the render and a footer band (view note) below it, wraps every line to the image width, and steps the font down to a floor before adding a line.
- The README opens with `media/render-hero.png`.
- Software-only and scene repositories (no single product) may use a scene render as the hero instead of a product model.

## 13. Storefront images

Two images, both made from `media/render-hero.png` by `python .kit/cards.py .`:

| File | Size | Purpose |
| --- | --- | --- |
| `media/card.png` | 800 x 800 | Square thumbnail for the organization profile page |
| `media/social-preview.png` | 1280 x 640, under 1 MB | GitHub social preview, shown when a repository link is shared |

- The social preview shows the area, name, one-line description, the first sentence of the pitch, the brand line and the repository address. Design Molecule repos read "Design Molecule · open hardware concept, TRL n"; OpenRatio repos read "OpenRatio · research and educational prototype, TRL n".
- GitHub has no API for the social preview. Upload it under the repository's Settings, Social preview, on release day.
- Regenerate both images whenever `render-hero.png` changes.

### Image quality

Every render, card and social preview must be clear and readable. `python .kit/image_qc.py` checks each one, and the release gate blocks on any failure:

| Check | Rule |
| --- | --- |
| Layout | Made by the current `photo_caption.py` or `cards.py`, which store the text layout in the PNG |
| Text inside the image | Every line at least 1.2 % of the image width from each edge; nothing runs off the side |
| No overlap | No line of text touches another line, and no caption text sits on the render |
| Text size | Render captions at least 1.05 % of the image width in pixel height (17 px at 1600 px); social preview text at least 16 px |
| Resolution | Renders at least 1200 px wide; card 800 x 800; social preview 1280 x 640 and under 1 MB |
| Sharpness | The render is not blurred or upscaled (edge sharpness at least 15 on the `image_qc.py` scale) |

Long titles and notes wrap to more lines rather than shrinking below the floor. The social preview shortens the pitch sentence with an ellipsis only if it cannot fit at the smallest size.

## 14. Public release

A repository goes public only when Amish approves it, and only after `python .kit/release_gate.py` passes. The gate checks:

1. `render.py --check` passes (document control, TRL cap, concept media).
2. Storefront: hero render, card, social preview under 1 MB, README leading with the hero, and every image passing the image quality check (section 13).
3. Issue templates in `.github/ISSUE_TEMPLATE/`: question, build report, design suggestion. The build report template restates that the design is a TRL 3 concept, not released for fabrication (OpenRatio: a research and educational prototype, not a medical device).
4. `CITATION.cff` valid, with an author ORCID.
5. License files match `project.yaml`.
6. No em dashes in the repository's own text.
7. BioMedical and OpenRatio repos use soft, non-clinical wording: "research and educational prototype, not a medical device".
8. No secrets anywhere in the history (gitleaks).
9. No links to sibling repositories that are still private.
10. REUSE files present (`REUSE.toml`, `LICENSES/`, `.github/workflows/reuse.yml`) and `reuse lint` passes (section 16).
11. `CITATION.cff` names exactly one license, because Zenodo rejects a list (section 17).

It warns, without blocking, when the README lacks a Safety heading or a "not for fabrication" statement, when `CITATION.cff` has no DOI yet, and when the README lacks the Zenodo DOI, REUSE or Software Heritage badge, so a person can confirm.

On release day, per repository:

- A signed, annotated tag `v0.<TRL>.0` on `main`.
- A GitHub release with short notes (what it is, TRL, status, licenses, how to cite) and a design pack, `<repo>-v0.<TRL>.0-design-pack.zip`, holding `cad/step`, `cad/drawings`, `docs/pdf`, `bom`, README, licenses and `CITATION.cff`.
- Description from the first sentences of `pitch` (350 characters at most), website `https://designmolecule.com` (OpenRatio: `https://openratio.ai`), topics from `project.yaml`.
- Before the first release, the repository is switched on in Zenodo (section 17), so the release is archived and gets a DOI.
- Visibility switched to public last, after the release exists.
- The social preview uploaded and the organization profile updated with the new cards.
- After the release: the concept DOI written to `CITATION.cff` and a Software Heritage save requested (section 17).

The internal working files (`CLAUDE.md`, `.kit/CLAUDE.md`, `.claude/commands/`, `docs/REVIEW.md`) stay public, and open "Proposed, awaiting Amish" items stay visible as open questions (Amish, 2026-09-27).

## 15. Authorship, citation and signing

- Amish Chadha is the author of every design, ORCID 0009-0000-8079-7141. Commits are authored as Amish Chadha <amish@designmolecule.com>.
- `CITATION.cff` lists Amish (with ORCID) first, then any credited contributors; `CONTRIBUTORS.md` and the README Credits section agree with it.
- `CITATION.cff` names one license: the hardware license (CERN-OHL-S-2.0), or the software license in a software-only repository. The full split between hardware and software licenses lives in `REUSE.toml` and the README. Once the repository is archived, `CITATION.cff` carries the concept DOI in `doi:`.
- Work done with Claude carries the trailer `Co-Authored-By: Claude <noreply@anthropic.com>` (with the model name), and the README Credits section says designs are developed with AI assistance.
- Every commit and tag pushed to GitHub is signed with Amish's SSH signing key, so GitHub shows it as Verified. Commits prepared elsewhere are re-signed on Amish's Mac before they are pushed.
- Once a repository is public, its history is never rewritten.

## 16. Licensing metadata (REUSE)

Every file states its copyright and license in a machine-readable way, following the REUSE Specification 3.3 (https://reuse.software). A repository is set up with:

```
python .kit/archive.py reuse
```

This writes three things and adds the REUSE and Software Heritage badges to the README badge line:

- `REUSE.toml`, built from the licenses in `project.yaml`. Everything is under the hardware license by default. Scripts, firmware, notebooks, web viewers, workflows and agent commands are under the software license. `cad/` and `electronics/` stay under the hardware license even where they are written as Python. The bundled IBM Plex fonts are OFL-1.1 (IBM Corp.). Copyright is "<first commit year> Amish Chadha".
- `LICENSES/`, with the full text of each license used (`reuse download`). The root `LICENSE` and `LICENSE-SOFTWARE` files stay for GitHub's license detection.
- `.github/workflows/reuse.yml`, which runs the REUSE check (fsfe/reuse-action) on every push and drives the README badge.

A new kind of file that falls outside these rules gets a new annotation in `REUSE.toml` rather than a header comment. `reuse lint` must pass before every commit that adds files, and the release gate enforces it.

## 17. Archiving and DOI (Zenodo and Software Heritage)

Every public repository is archived twice, so the design stays citable and retrievable if GitHub changes.

Zenodo (a citable DOI for each release):

1. Amish's Zenodo account is linked to GitHub. Before the first release, Amish switches the repository on in Zenodo (Account, GitHub). Only Amish changes Zenodo or GitHub settings.
2. Run `python .kit/archive.py zenodo`: it makes sure `CITATION.cff` names one license and adds the Zenodo DOI badge, which uses the GitHub repository ID and always points at the latest version. Zenodo reads its metadata (title, authors with ORCID, license, keywords) from `CITATION.cff`, and rejects the whole archive when that file lists several licenses.
3. Publish the GitHub release (section 14). Zenodo archives it within minutes and mints two DOIs: a version DOI for that release and a concept DOI that stands for all versions.
4. Check the Zenodo record: title, author and ORCID, license, keywords. If Zenodo shows "Citation metadata load failed", fix `CITATION.cff`, validate it with cffconvert and publish a new patch release (for example `v0.3.2`); a failed release is never re-used.
5. Run `python .kit/archive.py zenodo --doi <concept DOI>` and commit, so GitHub's "Cite this repository" and every future archive carry the concept DOI. Every later release gets its own version DOI automatically; the concept DOI never changes.

Software Heritage (permanent source archive):

1. After the repository is public, request a save at https://archive.softwareheritage.org/save/ (origin type git, the repository URL). Anonymous requests are limited to about ten an hour, so batches are spread out.
2. The Software Heritage badge on the README resolves once the save is accepted and ingested. Later pushes are picked up by its regular crawl.

OpenRatio repositories follow the same steps when Amish approves their release.

## 18. Prototype build plan (BLD) and the constructable design
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

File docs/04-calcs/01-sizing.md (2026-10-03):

---
doc_id: DWD-CAL-001
title: DewDrive sizing calculations
project: DewDrive
doc_type: Calculation
version: "0.7"
status: Draft
date: '2026-10-02'
author: Amish Chadha
license: CERN-OHL-S-2.0
revisions:
- version: "0.1"
  date: '2026-09-25'
  author: Amish Chadha
  change: First issue for TRL 3 (sorbent isotherm, night adsorption, day desorption and condenser, cyclic yield, stagnation and touch temperatures, salt containment, electrical energy, mass, wind, logging, cost)
- version: "0.2"
  date: '2026-09-25'
  author: Amish Chadha
  change: Recommendations accepted by Amish (DDR-002); design of record now through-flow with 25 wt % salt, drip screens and fan cut-out; paper evaluation of a low-emissivity screen
- version: "0.3"
  date: '2026-09-26'
  author: Amish Chadha
  change: Budget top-up approved by Amish (budget $520; R11 met); script re-run
- version: "0.4"
  date: '2026-10-01'
  author: Amish Chadha
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

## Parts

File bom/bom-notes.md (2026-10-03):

# BOM notes

Prices are TRL 3 estimates in USD, built up from typical small-quantity prices for each supplier type named in `bom.csv`. They are not quotes. Line numbers match the callouts in `media/exploded.png` and `media/cutaway.png`. Line 14 has no callout.

| Group | Items | Cost |
| --- | --- | --- |
| Collector: stand, box, glazing, trays, sorbent, condenser, water path, flap, drip screens, tray deck, hardware | 1 to 9, 14 to 16 | $504 |
| Night fan, power and logging | 10 to 13 | $135 |
| **Total parts cost** | 1 to 16 | **$639** |

The total of $639 is $119 over the $520 value-engineering target (`budget_usd`, a hypothetical control target, not a limit; set to $500 by Amish on 2026-09-25, DWD-DDR-001 D1, and $520 on 2026-09-26, DWD-DDR-002 D15). R11 is over its target. DWD-CAL-001 (J1) reads this file and checks the total. The total was $515 before the design for construction (DWD-DDR-003, which added line 16 and repriced others, to $620) and rose by $19 with the decisions of 2026-10-02, below.

Changes for DWD-DDR-002 (from $488): line 4 rose from $10.00 to $11.50 per tray for the EPDM edge gasket and a share of the sealing baffle that makes the night air pass through the beds (D9); line 5 rose from $28 to $29 for the new mix of 3.0 kg gel and 1.0 kg CaCl₂ (D10); new line 15 adds four black drip screens with brine sumps at $5 each (D11). The anchors in line 1 are now the default wind restraint (D13).

Changes at TRL 3 from TRL 2 ($475): line 1 rose by $10 to include two auger ground anchors; line 6 rose by $3 after a material build-up.

Every part that touches the water (items 5 to 8 and the sealant in item 14) must be food-grade or food-contact rated. The drip screens (item 15) hold brine and must be kept apart from the water path.

Decided by Amish on 2026-10-02 (DWD-DEC-001) and carried into this file the same day:

- Line 3 (glazing lid): the sheet is twin-wall polycarbonate rated 130 °C or more (item 3), or a 120 °C sheet only if the supplier's data and the inner-skin temperature measured at the TRL 4 stagnation test both show it stays inside its rating. Price basis: a 130 °C grade at about $48 per square metre (an estimate of about 50 % above the $32 per square metre of a standard sheet; no supplier quote yet) over 1.09 m², which raises the sheet from about $35 to about $52, so line 3 rises from $65 to $82. Re-price from a quote when one is available.
- Line 14 (hardware and consumables): one printed outdoor vinyl label, 150 x 50 mm, "Empty before lifting: remove trays, sorbent and deck", on the east wall (item 2), about $2 (estimate), so line 14 rises from $32 to $34. The label is modelled as a 0.5 mm plate in `cad/src/model.py` and drawn in the picture for build step 16; its mass (about 5 g) is counted in the hardware group.
- The drip screens stay black (item 4); the paper study of a passive vent (DWD-CAL-001, section D) finds no modest-cost passive remedy, so the low-emissivity screens are dropped.

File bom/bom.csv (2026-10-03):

item | qty | spec | supplier | unit_cost_usd | make_buy | notes
1 Stand | 1 | Galvanized steel angle 30 x 30 x 3 mm (about 10 m): two rails under the box's east and west edges, four legs, two side braces, two end cross members and a south diagonal brace, bolted with M8 bolts; four 120 x 120 x 5 mm steel foot plates with angle cleats; two auger ground anchors with ratchet straps (or about 50 kg of local ballast, DWD-CAL-001 H2) (DWD-DDR-003) | Steel stockist or hardware shop; anchors from a farm or fencing supplier | 48.00 | make | Angle about $2.50/m; foot plates about $6; anchors about $8 each; bolts are in line 14; ballast (stones or sandbags) is local and not priced
2 Insulated box walls | 1 | Four panels, 133 mm tall and 40 mm thick: 6 mm exterior plywood skins glued to a 28 mm core of softwood battens (28 x 44 mm bottom, 28 x 20 mm top, 28 x 28 mm posts) with 25 mm PIR foam between; north and south panels 1,100 mm long, east and west 920 mm; 800 x 40 mm inlet opening in the south panel, 140 x 44 mm outlet slot in the north panel; six M6 threaded inserts in the east and west bottom battens; painted (DWD-DDR-003) | Timber merchant and builders' merchant | 68.00 | make | One 1.2 x 2.4 m plywood sheet about $35; battens about $10; PIR offcut about $10; exterior paint about $10; inserts and adhesive about $3
3 Glazing lid | 1 | 10 mm UV-stabilized twin-wall polycarbonate rated 130 C or more in service, 1,096 x 996 mm, flutes running down the slope, in an aluminium U-channel edge frame (12 mm deep) with mitred corners; three stainless butt hinges on the north edge; two over-centre latches on the south edge; EPDM seal on the wall tops | Greenhouse or glazing supplier; hardware shop | 82.00 | buy | Sheet about $48/m2 for a 130 C-rated grade (estimate: about 50 % above the $32/m2 of a standard 120 C sheet; no supplier quote yet); U-channel about $12; hinges about $6; latches about $8; seal about $4; rated above the 122 C stagnation temperature (DWD-CAL-001 D1); a 120 C sheet is allowed only with supplier data and a measured inner-skin temperature (DWD-DEC-001, 2026-10-02)
4 Sorbent trays | 4 | Aluminium pans 490 x 430 x 25 mm folded from 1 mm sheet with an 8 mm inward bottom lip and a hemmed top edge; floor of 1 mm perforated aluminium (about 50 % open) with a fine stainless woven mesh (1 mm aperture) on top; top painted high-temperature matt black, underside left bare; EPDM gasket tape under the lip | Local sheet-metal shop; mesh from a wire-cloth supplier; gasket tape from a hardware shop | 14.00 | make | Price each; pan about $5; perforated floor about $5; mesh about $3; gasket tape about $1
5 Composite sorbent | 1 | About 4 kg total: 3.0 kg mesoporous silica gel beads (2 to 5 mm, about 1.0 cm3/g pore volume) impregnated with 1.0 kg food-grade anhydrous CaCl2 (25 wt %, DWD-DDR-002) | Desiccant supplier (silica gel); food-additive or brewing supplier (CaCl2 E509) | 29.00 | make | Silica gel about $8/kg; CaCl2 about $5/kg
6 Condenser plate with fins | 1 | 2 mm aluminium plate 1,080 x 980 mm, screwed up into the wall bottom battens on EPDM gasket tape so it closes the bottom of the box; 21 fins 1 mm thick, 100 mm deep and 920 mm long, each with a 10 mm folded foot bonded with high-temperature epoxy and fixed with closed-end aluminium rivets at 150 mm pitch; food-safe coating on the wetted top face (DWD-DDR-003) | Aluminium stockist and local sheet-metal shop | 82.00 | make | Plate about $40; fin strip about $25; rivets and epoxy about $7; coating about $10; largest single cost
7 Condensate gutter and drain | 1 | Aluminium gutter 1,020 mm long folded from 1 mm sheet: 30 mm flange on the plate and 16 mm upstand against the south wall, sealed with food-grade silicone; food-grade bulkhead fitting with a 12 mm hose barb through the gutter and plate; 1 m food-grade silicone tube, 12 mm bore | Sheet-metal shop and plumbing supplier | 19.00 | make | Gutter about $8; fitting about $6; tube about $5
8 Collection bottle | 1 | 10 L food-grade HDPE jerrycan with screw cap and tube grommet | Local market or camping supplier | 12.00 | buy
9 Inlet flap | 1 | Aluminium flap 840 x 60 mm, 1.5 mm, covering the 800 x 40 mm inlet opening; piano hinge along its top edge; EPDM seal; two over-centre latches | Local sheet-metal shop and hardware shop | 15.00 | make
10 Night fan, hood and outlet flap | 1 | 12 V 120 mm fan, about 2 W, IP55; hood 160 x 64 x 130 mm folded from 1 mm aluminium, screwed over the outlet slot on the north wall; hinged 140 x 125 mm outlet flap with EPDM seal over the fan (DWD-DDR-003) | Electronics distributor and sheet-metal shop | 19.00 | buy | Fan about $10; hood about $5; flap and hinge about $4
11 PV panel and pole | 1 | 10 W 12 V monocrystalline panel, about 340 x 250 mm; 25 x 25 x 2 mm steel square tube pole bolted to the north-east leg on two 8 mm spacers; pole-top tilt bracket (DWD-DDR-003) | Solar or electronics distributor; steel stockist | 28.00 | buy | Panel about $18; tube about $5; bracket about $5
12 Electronics box | 1 | IP65 box with 12 V PWM solar charge controller, 12.8 V 6 Ah LiFePO4 battery with built-in BMS and fuse, ESP32 logger with RTC and microSD, MOSFET fan switch; on a 3 mm aluminium backing plate bolted to the north-west leg | Electronics distributor | 68.00 | buy | Battery about $30; controller about $10; logger parts about $15; box and fuse about $10; backing plate about $3; firmware beyond a sketch is TRL 4 work
13 Sensors | 1 | Air temperature and RH sensor (SHT4x class) in a radiation shield on an arm from the backing plate; two waterproof DS18B20 probes for bed and condenser temperature | Electronics distributor | 20.00 | buy | Probes too small to model
14 Hardware and consumables | 1 | Galvanized M8 bolts, nuts and washers for the stand (about 26); six M6 bolts into the wall inserts; stainless M5 button-head screws for the plate; stainless wood screws; aluminium rivets; food-grade silicone sealant; EPDM gasket tape and lip seal; cable glands; cable ties; one weather-resistant adhesive label, 150 x 50 mm, reading EMPTY BEFORE LIFTING: remove trays, sorbent and deck, on the box's east wall (DWD-DEC-001, item 2) | Hardware shop | 34.00 | buy | No exploded-view callout; label about $2 (printed outdoor vinyl, estimate)
15 Drip screens | 4 | Two staggered layers of 20 x 6 mm U-channels bent from 0.5 mm aluminium flashing, 30 mm pitch, running down the slope, on four 15 x 2 mm cross straps between two 1 mm side plates; a closed brine sump at the low end and an end plate at the high end, each riveted to a bar of the tray deck; painted high-temperature matt black; no line of sight from bed to condenser (DWD-DDR-002, DWD-DDR-003) | Builders' merchant (flashing coil) and local sheet-metal shop | 6.00 | make | Price each; flashing about $2.50; plates and straps about $3; rivets about $0.50
16 Tray deck and wall ledges | 1 | Frame of 20 x 5 mm aluminium flat bar on edge (1,016 x 916 mm outside, with a centre cross), corners joined with small riveted angle brackets; 1 mm aluminium sealing baffle sheet riveted on top with four 474 x 414 mm openings; EPDM lip seal round its edge; two 15 x 15 x 2 mm aluminium angle ledges screwed to the east and west walls. The deck, with the drip screens hung under it, lifts out (DWD-DDR-003) | Aluminium stockist and local sheet-metal shop | 35.00 | make | Flat bar about $15; baffle sheet about $15; ledges and brackets about $5

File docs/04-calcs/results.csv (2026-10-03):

id | requirement | value | target | status
R1 | Water at the design point | 0.57 L/day (C3) | >= 0.5 L/day | met
R2 | Water in dry nights | 0.45 L/day at 25 % RH (C4) | >= 0.25 L/day at 25 % RH | met
R3 | Sun-only regeneration | bed 112 C at noon (C2) | >= 75 C by midday | met
R4 | Own electrical loads | 23.6 Wh/day against 35 Wh/day PV; 2.6 days autonomy (F1, F2) | <= 30 Wh/day; >= 2 days | met
R5 | Condenser rise | 12.1 K (C2) | <= 15 K | met
R6 | Water quality | materials food-grade by selection; chloride carry-over needs a water test | food-grade; Cl < 250 mg/L | not verifiable at TRL 3
R7 | Salt containment | pores fill at 71 % RH; 43 % of pore volume after one 90 % RH night; 50 % after three with the fan rule; sumps 0.58 L (E2 to E6) | no brine leaves the tray and drip-screen assembly after a 90 % RH night | met
R8 | Two actions per day | open flaps at dusk, close at dawn; fan on a timer with a humidity cut-out | 2 actions, <= 5 min | met
R9 | Portable | box 35.2 kg with everything inside; 23.4 kg with the trays and deck lifted out; total 60.2 kg (G1, G2) | box <= 35 kg lifted with trays and deck out (restated 2026-10-02); stand separable | met
R10 | Survive the site | two anchors of 98 N (default) or 40 kg ballast for 20 m/s (H2 to H4); UV and 300 cycles need supplier data and test | stable at 20 m/s; UV; 300 cycles | not verifiable at TRL 3
R11 | Cost | $639 (J1) | <= $520 (top-up, 2026-09-26) | not met
R12 | Record performance | 8640 records, 0.41 MB (I1) | 5 min for 30 days | met
R13 | Protect users | glazing outer about 57 C at stagnation; fins up to 47 C; 12.8 V DC (D1 to D3) | touched surfaces <= 60 C; < 60 V DC | met

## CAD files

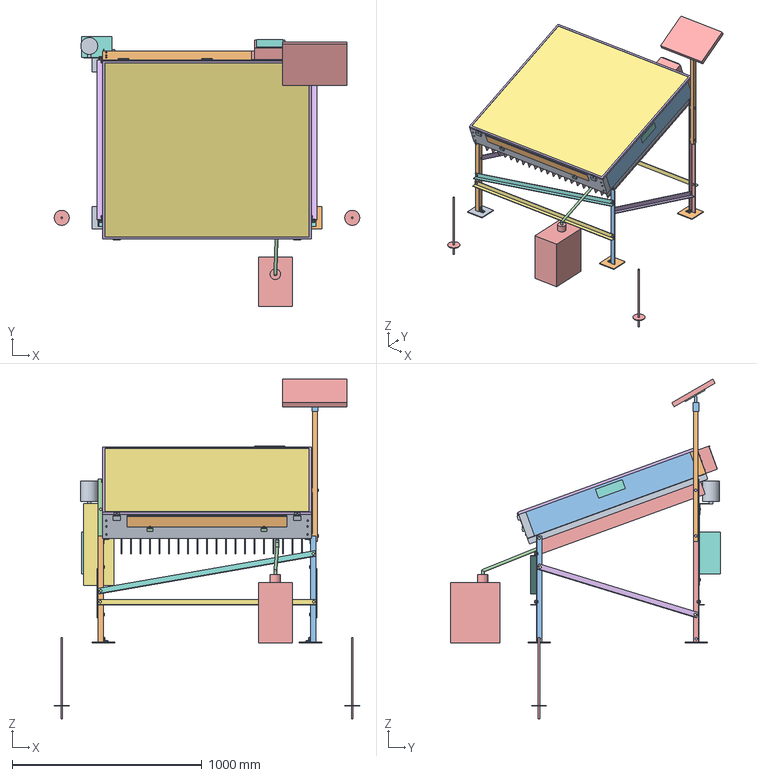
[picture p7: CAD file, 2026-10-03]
cad/step/dewdrive-assembly.step
1610.0 x 1421.9 x 1790.5 mm

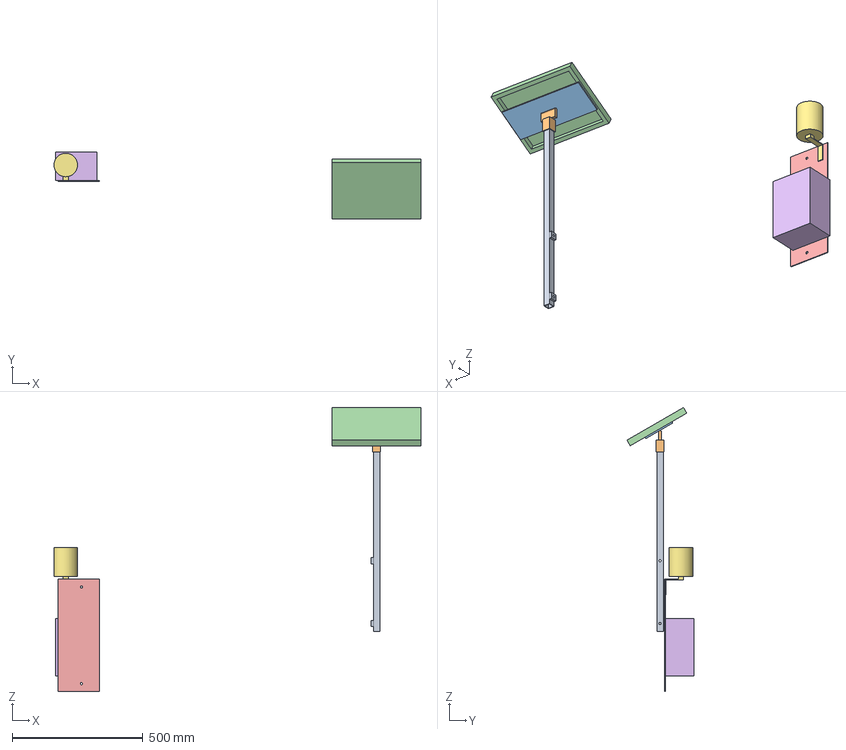
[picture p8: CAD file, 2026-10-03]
cad/step/power-and-logging.step
1403.4 x 256.8 x 1086.2 mm

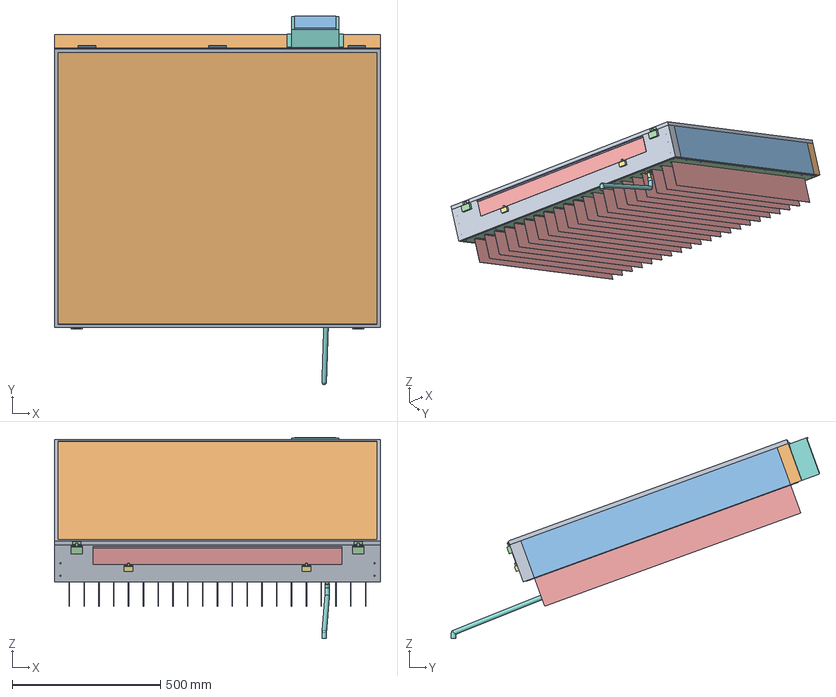
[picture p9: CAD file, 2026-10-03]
cad/step/collector-box.step
1100.0 x 1243.4 x 678.8 mm

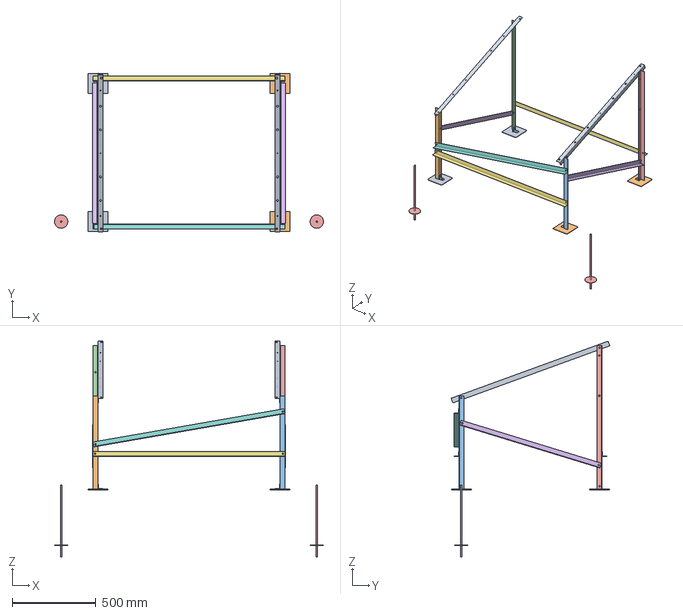
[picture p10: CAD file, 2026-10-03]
cad/step/stand.step
1609.9 x 950.0 x 1291.4 mm

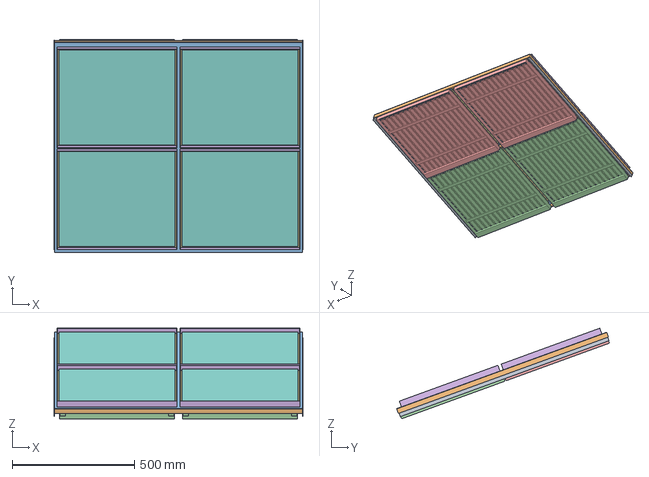
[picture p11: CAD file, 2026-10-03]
cad/step/sorbent-trays.step
1020.0 x 871.8 x 371.1 mm

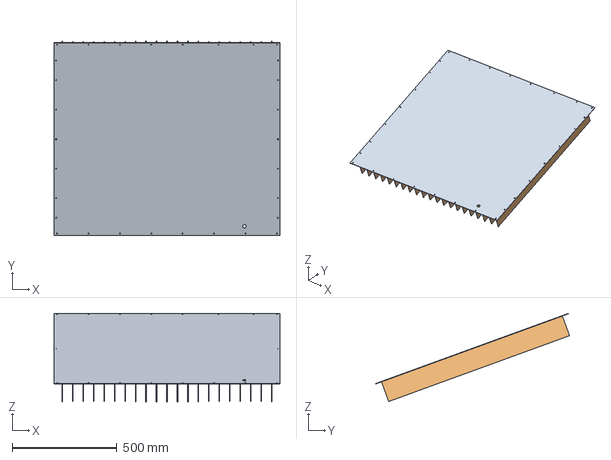
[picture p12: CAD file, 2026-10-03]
cad/step/condenser.step
1080.0 x 927.6 x 420.8 mm

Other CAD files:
cad/stl/collector-box.stl
cad/stl/condenser.stl
cad/stl/dewdrive-assembly.stl
cad/stl/power-and-logging.stl
cad/stl/sorbent-trays.stl
cad/stl/stand.stl

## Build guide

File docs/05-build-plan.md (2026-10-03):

---
doc_id: DWD-BLD-001
title: DewDrive prototype build plan
project: DewDrive
doc_type: Build plan
version: "0.4"
status: Draft
date: '2026-10-02'
author: Amish Chadha
license: CERN-OHL-S-2.0
revisions:
  - version: "0.1"
    date: '2026-10-01'
    author: Amish Chadha
    change: First build plan, with pictures by component and step; design made constructable (DWD-DDR-003)
  - version: "0.2"
    date: '2026-10-01'
    author: Amish Chadha
    change: Budget treated as a value-engineering target; cross-references updated
  - version: "0.3"
    date: '2026-10-02'
    author: Amish Chadha
    change: 'Decisions of 2026-10-02 carried in: glazing rated 130 °C or more (sections 3.9, 3.19, stop S3); box labelled to be emptied before lifting (step 16, stop S4) (DWD-DEC-001, items 2 and 3)'
  - version: "0.4"
    date: '2026-10-02'
    author: Amish Chadha
    change: 'Follow-ups of the 2026-10-02 decisions: the "Empty before lifting" label drawn and fitted in step 16 (bill of materials line 14); glazing line repriced for a 130 °C sheet; parts cost updated'
---

# DewDrive prototype build plan

**Plan, not yet built.** How to build the first proof-of-concept prototype, component by component. Building and testing to it is TRL 4 work. Decisions still to be made are kept in the design decisions register ([docs/06-design-decisions.md](06-design-decisions.md)), not here.

## 1. What you are building

Figure 1. Every component, pulled apart and numbered in build order

*Figure 1. Every component pulled apart and numbered in build order: the box in the middle, the stand on the left, power, logging and water on the right.*

The prototype is one DewDrive: a glazed, insulated box 1,100 x 1,000 mm, tilted 20° toward the sun on a bolted steel stand. Inside the box, four black trays of sorbent sit on a removable deck, with a drip screen hung under each tray; the box's aluminium floor is the condenser, with fins underneath. A small fan in a hood on the north wall draws night air through the beds; a 10 W panel and a battery box on the stand's north legs run the fan and the logger. Figure 1 shows the 31 components in the order you make or fit them. Twenty are made in a home or small workshop from plywood, softwood, foam board, aluminium sheet, bar and angle, and galvanized steel angle: the four wall panels, the condenser plate and fins, the gutter, the ledges, the tray deck and baffle, the drip screens, the trays, the lid frame, both flaps, the fan hood, and every stand part. The sorbent is mixed by hand. Everything else is bought and fitted. The work is woodworking with glue and screws, cutting, folding, drilling and riveting thin aluminium, drilling and bolting steel angle, and wiring bought 12 V modules. The parts cost about $639 from the bill of materials.

> **Safety:** The sorbent is made with calcium chloride, which irritates eyes and skin and gets hot as it dissolves; wear gloves and eye protection. In sun the inside of the box passes 110 °C: open the lid and handle trays only when cool. The 12.8 V lithium iron phosphate battery must be fused at the battery. The tilted lid catches the wind: anchor the stand before the box goes on it. Cut aluminium and steel edges are sharp; deburr everything. Harvested water must be tested and treated before anyone drinks it.

## 2. What changed to make it buildable

The concept showed what DewDrive does; many of its parts could not be made or fixed as drawn. Each change below keeps what the unit does, and all of them are recorded in decision record DWD-DDR-003, open for Amish's review.

*Table 1. Changes from the concept.*

| Component | The concept had | The buildable design has | Why |
| --- | --- | --- | --- |
| Condenser plate | A plate inside the walls, overlapping them, with no fixing | The plate closes the bottom of the box; the walls stand on it on gasket tape and 24 screws go up into the walls (Figure 5) | Seals the box and needs no extra frame |
| Walls | A solid block | Four sandwich panels with softwood battens round their edges, screwed at the corners (Figures 2 to 4) | Gives timber wherever a screw goes |
| Tray support | A thin baffle sheet on two loose rails | A lift-out deck of aluminium bars with the baffle riveted on top, resting on two wall ledges (Figures 12 to 14) | Carries four full trays and lifts out for cleaning |
| Drip screens | Floating under the trays with nothing holding them | A riveted frame hung from the deck bars by its sump and end plate (Figures 15 and 16) | Comes out with the deck; never touches the condenser |
| Fins | Thin strips standing on their edges | Fins with a folded foot, bonded and riveted (Figures 7 and 8) | An edge cannot be fixed; a foot can |
| Gutter and drain | A closed channel water could not enter, draining through the wall | A folded gutter in the low corner and a drain fitting down through the floor (Figures 9 and 10) | Water leaves by gravity without touching wood |
| Outlet | A separate outlet flap beside the fan, which would have let the fan draw air past the beds | One slot under the deck, into a hood that holds the fan; the outlet flap closes the fan opening (Figures 22 and 23) | All the air now passes down through the beds |
| Inlet opening | No room above it for the wall's top edge | The same opening 20 mm lower, still above the deck (Figure 21) | The wall keeps a solid top for the lid seal |
| Lid | A loose sheet | A sheet in an aluminium edge frame, with hinges, latches and a seal (Figures 18 and 19) | Holds the sheet and seals the box by day |
| Stand | Rails running through the box, no joints, no bracing | Rails under the box edges bolted into the walls; legs, braces, cross members and a diagonal, all bolted (Figures 24 to 35) | Every joint is face to face and bolted; the frame cannot rack |
| PV pole, electronics | The pole through the box; the electronics in mid-air | A square tube on spacers on the north-east leg; a backing plate on the north-west leg (Figures 36 to 39) | Fixed to the stand, clear of the box |
| Trays | Thick blocks with a sagging mesh floor | Folded 1 mm pans with a perforated floor under the mesh (Figure 17) | Same size and bed; the floor carries the sorbent |

## 3. Making the components

Make and check each component before the assembly step that needs it. Sizes are in millimetres. "Box frame" heights are measured up from the bottom edge of the walls, as if the box lay flat on a bench; "east" and "west" are as seen standing south of the unit, facing the glazing. Workshop tolerance is 1 mm for wood and 0.5 mm for metal unless a step says otherwise; drawings do not carry tolerances before TRL 4.

### 3.1 Wall panels (make 4)

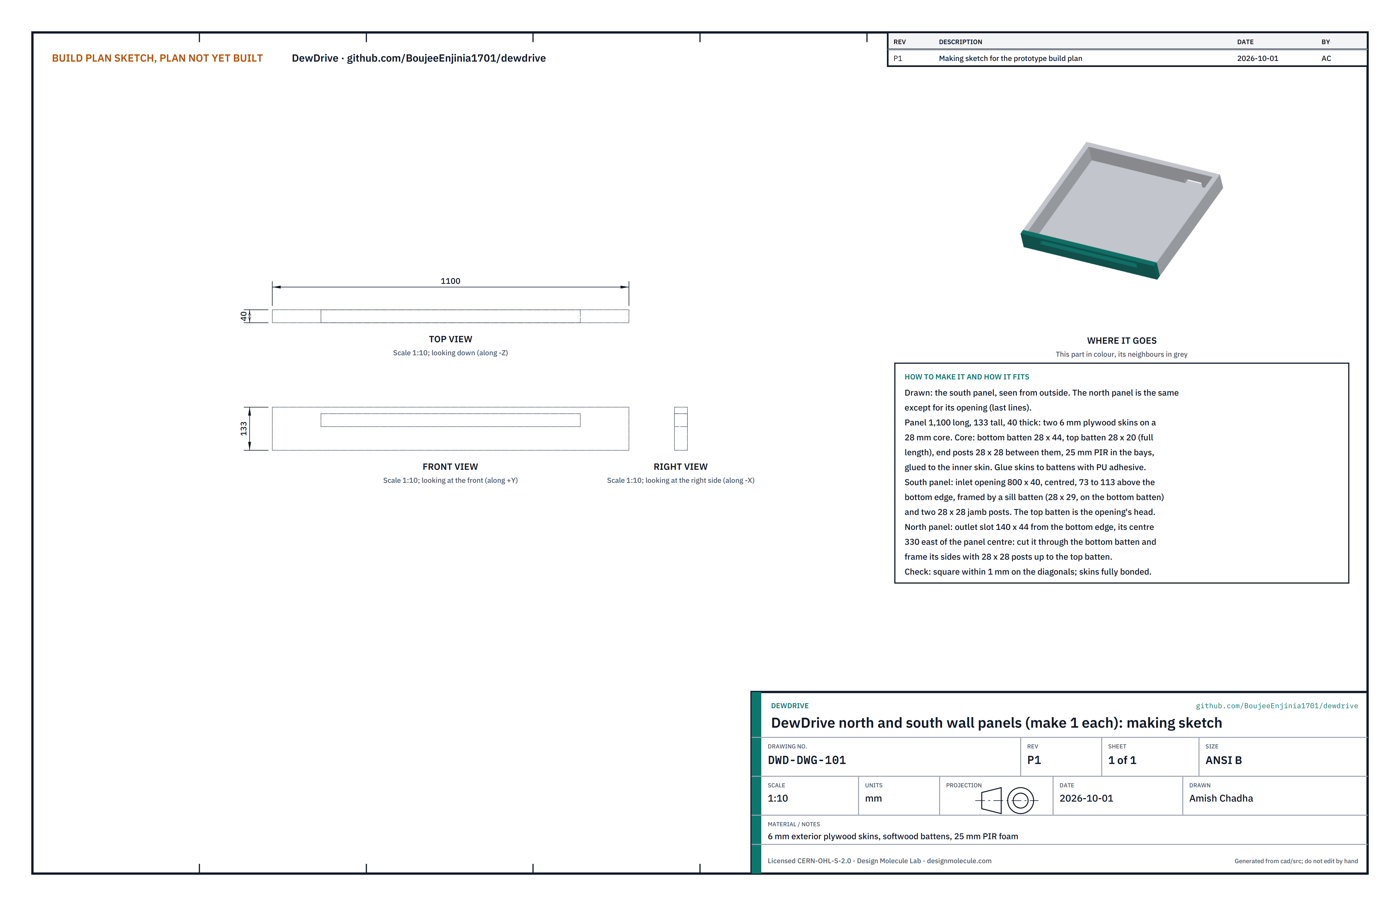
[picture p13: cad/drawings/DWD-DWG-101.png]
Figure 2. Making sketch of the north and south panels


*Figure 2. North and south panels (DWD-DWG-101); the south panel has the inlet opening, the north panel the outlet slot.*

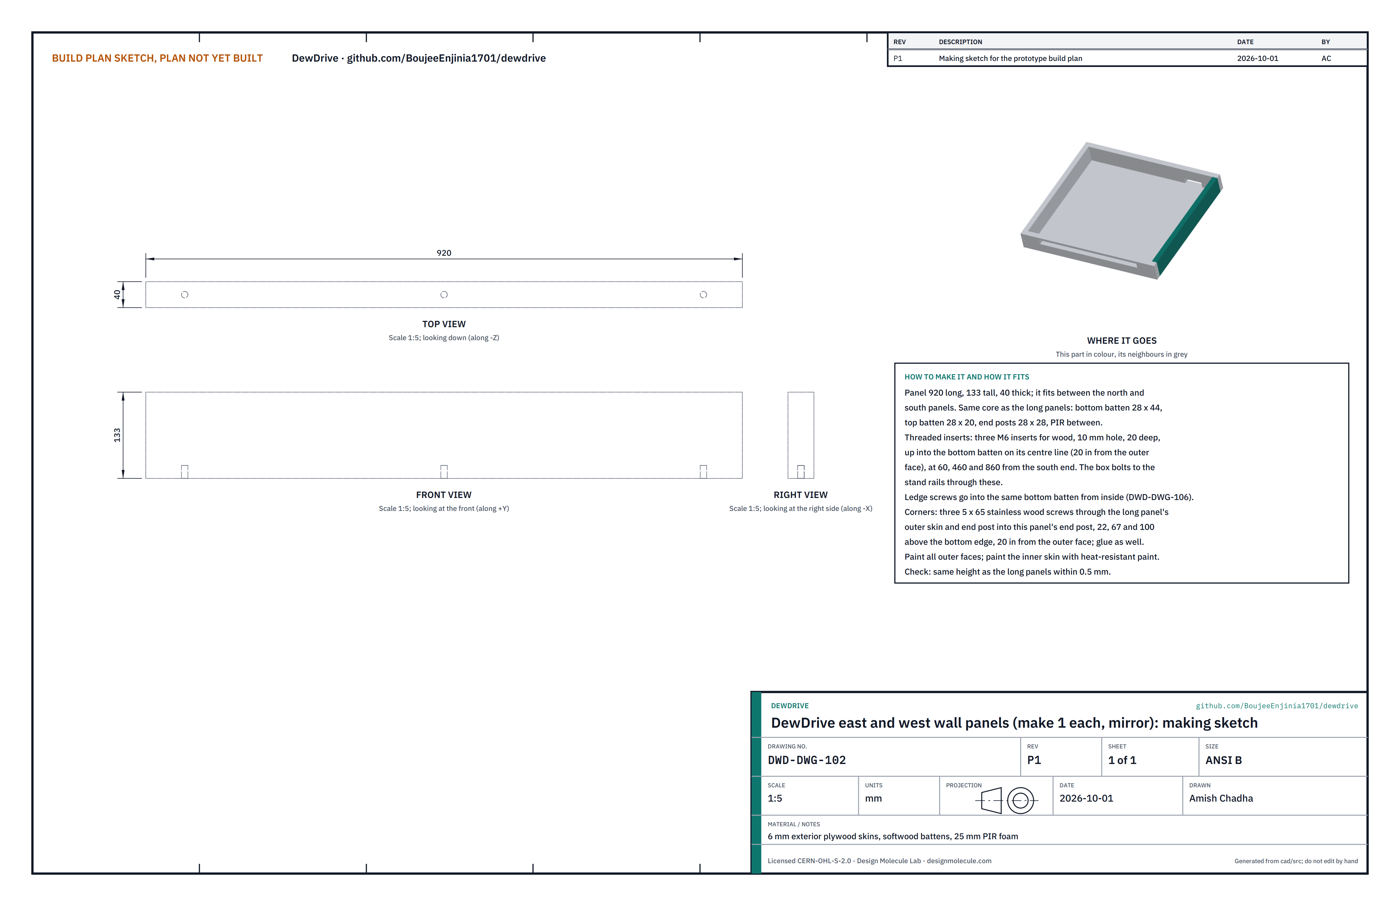
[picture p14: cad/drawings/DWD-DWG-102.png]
Figure 3. Making sketch of the east and west panels


*Figure 3. East and west panels (DWD-DWG-102), with the threaded inserts for the stand bolts.*

**What it is and what it is made from.** The four insulated sides of the box, each 133 tall and 40 thick: two 6 mm exterior plywood skins glued to a 28 mm core of planed softwood battens, with 25 mm PIR foam board in the bays. North and south panels are 1,100 long; east and west panels are 920 long and fit between them.

**How to make it.**

1. Cut eight skins from one 1.2 x 2.4 m sheet of 6 mm exterior plywood: four 1,100 x 133 and four 920 x 133.
2. Cut the battens for each panel: a bottom batten 28 x 44 and a top batten 28 x 20, both full length; and two end posts 28 x 28, 69 long, to fit between them.
3. South panel: cut the inlet opening, 800 x 40, centred along the panel, from 73 to 113 above the bottom edge, through both skins. Frame it with a sill batten 28 x 29 sitting on the bottom batten and two 28 x 28 jamb posts beside the opening; the top batten is the opening's head.
4. North panel: cut the outlet slot, 140 wide and 44 tall from the bottom edge, its centre 330 east of the panel's centre. Cut the bottom batten away over the slot and fit a 28 x 28 post each side of it, from the bottom batten up to the top batten.
5. Glue the battens to the inner skin with polyurethane construction adhesive. Glue PIR board into the bays against the inner skin; it leaves a 3 mm air gap under the outer skin. Glue the outer skin on and weight the panel flat until set.
6. East and west panels: drill three 10 mm holes 20 deep up into the bottom batten, on its centre line (20 in from the outer face), at 60, 460 and 860 from the south end, and screw in M6 threaded inserts for wood.
7. Paint the outer faces with exterior paint and the inner faces with heat-resistant paint.

**How it fits the parts next to it.**

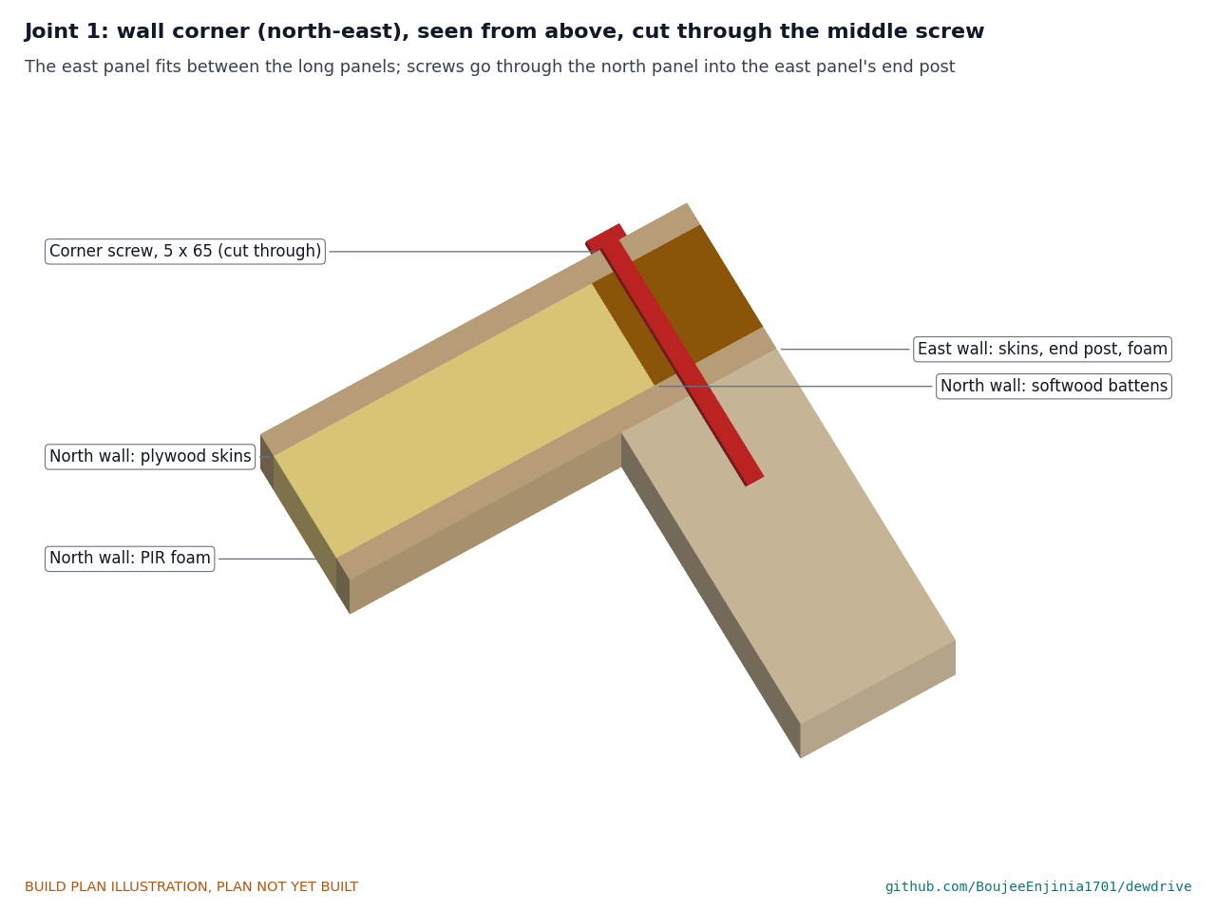
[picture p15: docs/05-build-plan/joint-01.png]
Figure 4. Joint 1: the north-east corner, cut through a screw


*Figure 4. The east panel fits between the long panels; each corner screw passes through the north panel and into the east panel's end post.*

The east and west panels fit between the north and south panels. At each corner, three 5 x 65 stainless wood screws go through the long panel's outer skin and end post into the short panel's end post, 22, 67 and 100 above the bottom edge and 20 in from the outer face, with adhesive on the joint. The bottom battens take the condenser plate screws and the ledge screws; the top battens take the lid hinges and latches.

**Check before moving on.** The assembled box is square within 2 mm on its diagonals and its top and bottom edges are flat within 1 mm.

### 3.2 Condenser plate and fins

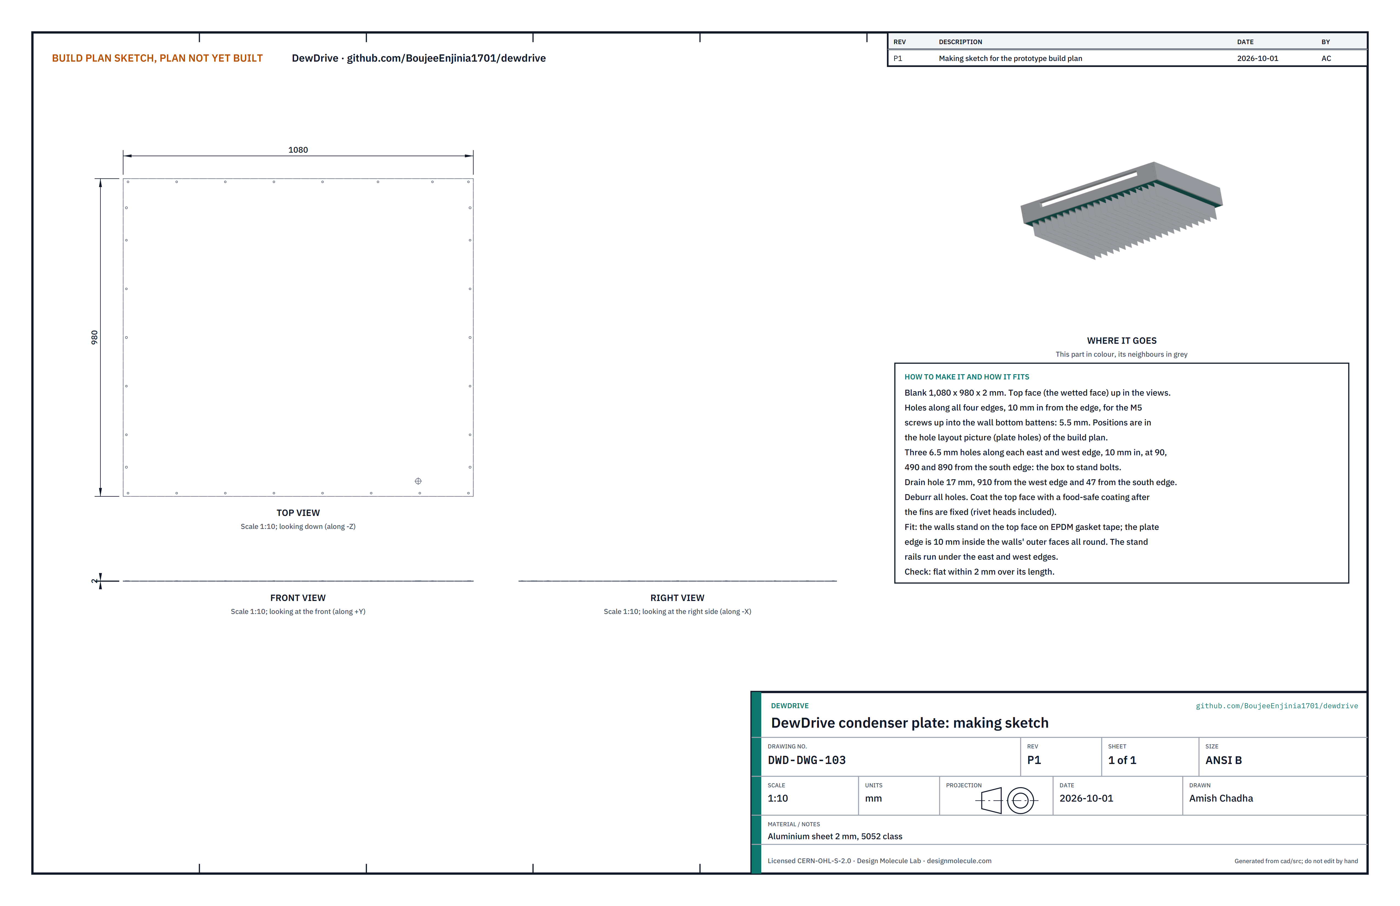
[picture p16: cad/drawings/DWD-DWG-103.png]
Figure 5. Making sketch of the condenser plate


*Figure 5. Condenser plate (DWD-DWG-103).*

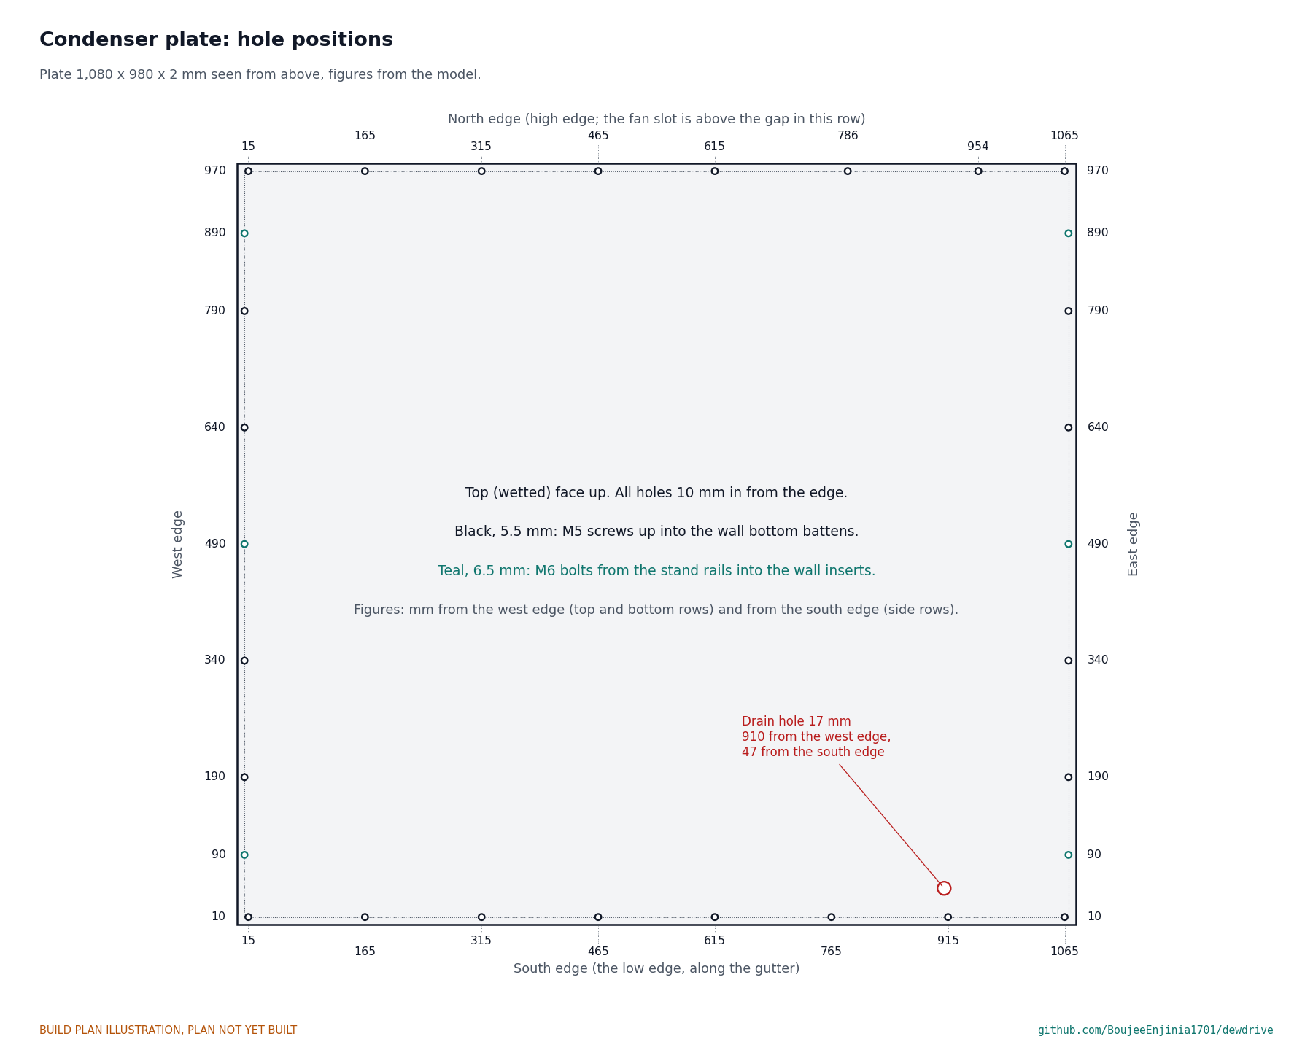
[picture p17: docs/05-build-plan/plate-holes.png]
Figure 6. Hole positions in the condenser plate


*Figure 6. Every hole in the plate, measured from the west and south edges.*

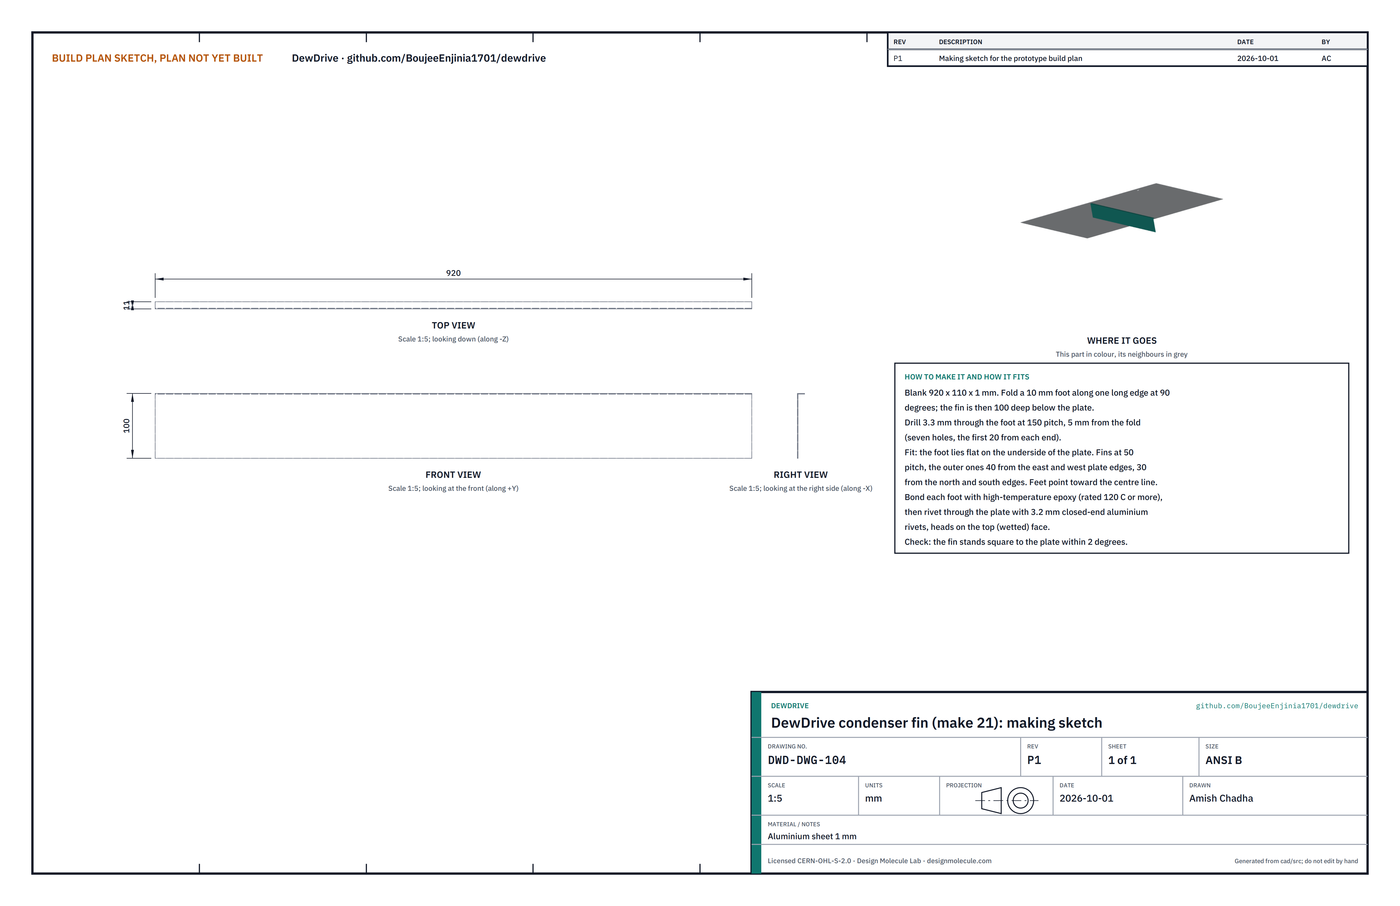
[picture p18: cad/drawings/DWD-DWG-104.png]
Figure 7. Making sketch of a fin


*Figure 7. Condenser fin (DWD-DWG-104).*

**What it is and what it is made from.** The floor of the box, where the vapour condenses, with 21 fins underneath that keep it cool in the box's own shade. Plate: aluminium sheet 2 mm, 5052 class, 1,080 x 980. Fins: aluminium sheet 1 mm, each 920 x 110 before folding.

**How to make it.**

1. Cut the plate square. Mark and drill the holes of Figure 6, all 10 in from the edges: 24 holes of 5.5 mm for the wall screws, six of 6.5 mm for the stand bolts (three along each east and west edge, at 90, 490 and 890 from the south edge), and the 17 mm drain hole 910 from the west edge and 47 from the south edge. Deburr.
2. Cut 21 fin blanks 920 x 110. Fold a 10 mm foot along one long edge of each, at 90°. Drill seven 3.3 mm holes through each foot, 5 from the fold, at 150 pitch, the first 20 from each end.
3. Turn the plate over (top face down) on a clean bench. Mark the fin lines at 50 pitch, the outer two 40 from the east and west edges; each fin runs 30 short of the north and south edges. The feet point toward the centre line.
4. Bond each foot with high-temperature epoxy (rated 120 °C or more), drill through the plate from the foot's holes, and fix with 3.2 mm closed-end aluminium rivets, heads on the top face.
5. Once the epoxy has cured, clean the top face and coat it, rivet heads included, with a food-safe coating.

**How it fits the parts next to it.**

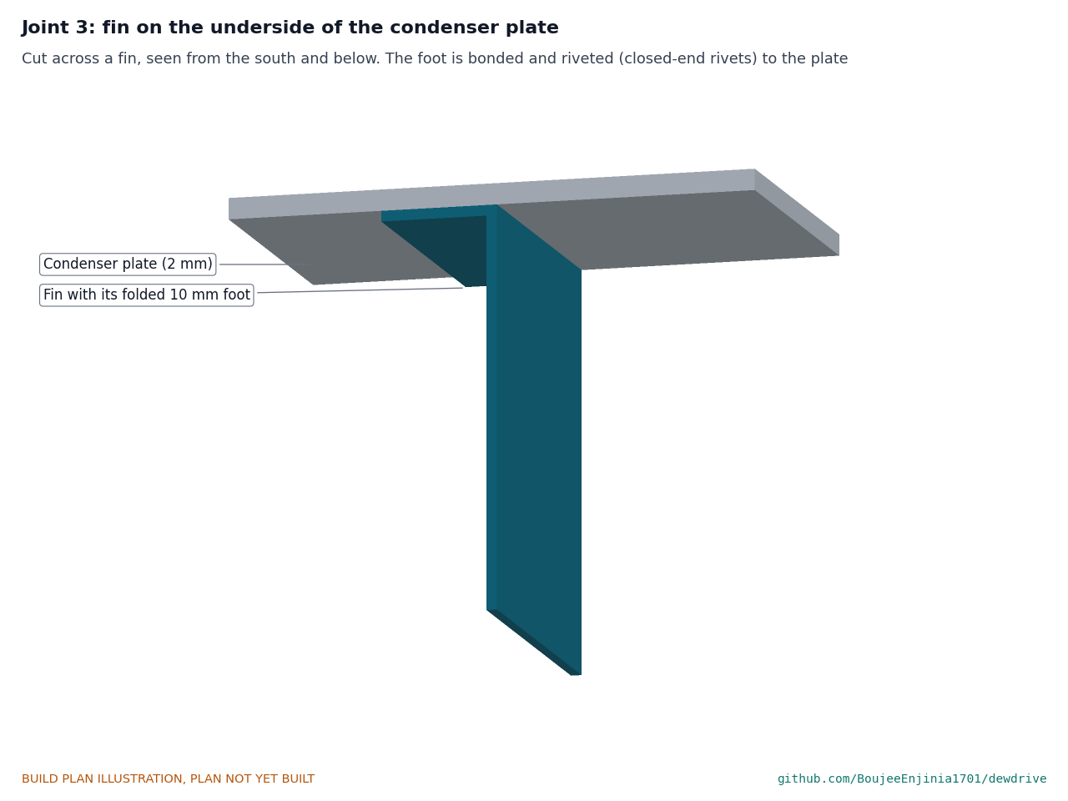
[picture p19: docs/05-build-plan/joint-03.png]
Figure 8. Joint 3: a fin on the underside of the plate


*Figure 8. The fin's foot lies flat on the underside of the plate.*

The walls stand on the top face on EPDM gasket tape, the plate edge 10 inside the walls' outer faces all round; M5 button-head stainless screws go up through the plate into the bottom battens (step 3). The stand rails run under the east and west edges, where three bolts go up through the plate into the wall inserts (Figure 24).

**Check before moving on.** Every fin stands square to the plate within 2°, and the drain hole sits between two fins with room for the fitting's nut.

### 3.3 Gutter and drain fitting

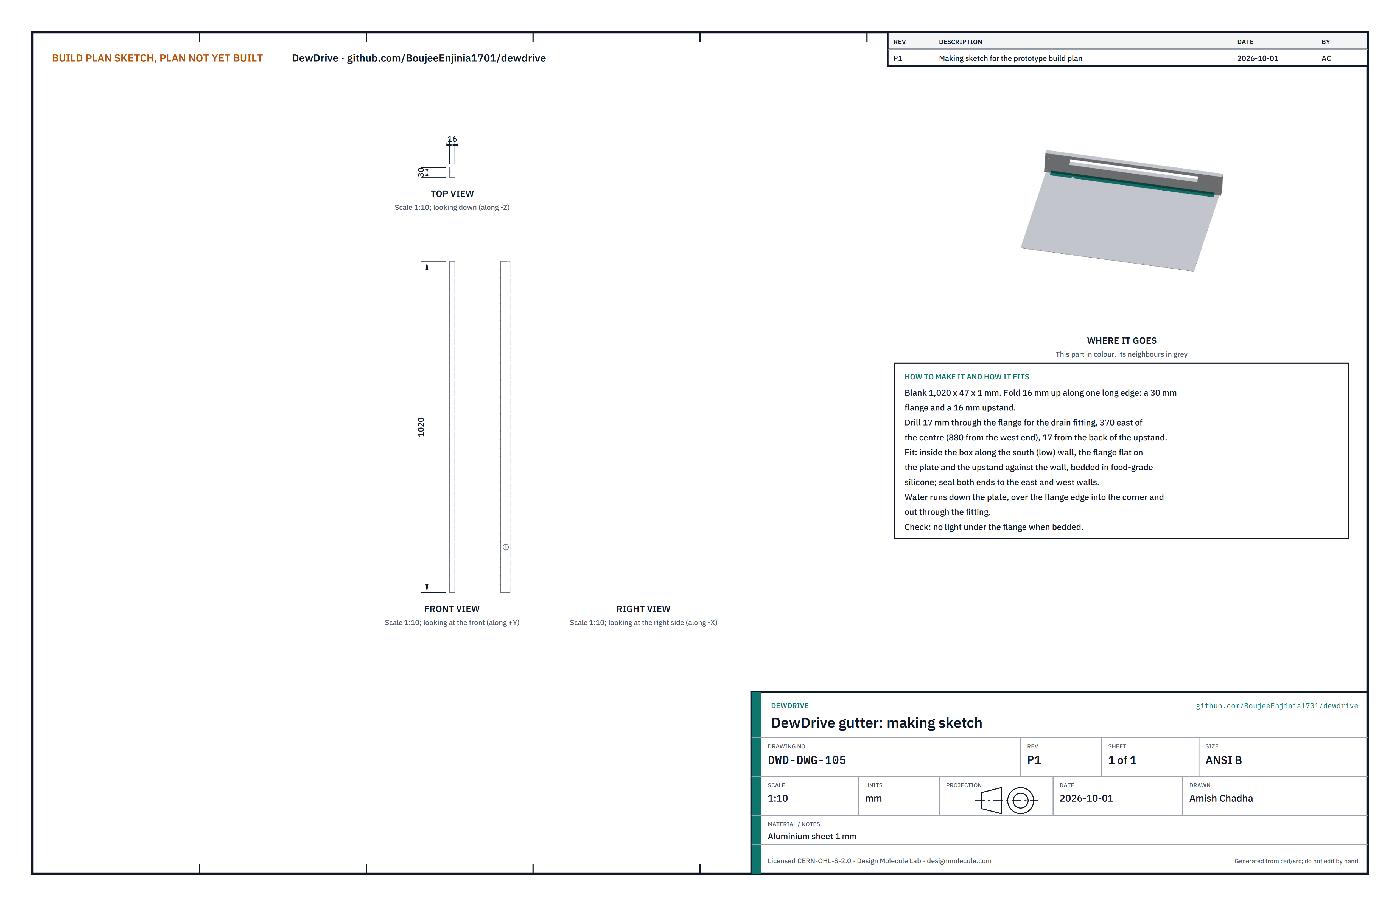
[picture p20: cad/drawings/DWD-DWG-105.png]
Figure 9. Making sketch of the gutter


*Figure 9. Gutter (DWD-DWG-105).*

**What it is and what it is made from.** A folded aluminium angle that lines the low (south) corner of the box, where the condensate collects, and a bought food-grade bulkhead fitting with a 12 mm hose barb that drains it through the floor. Gutter: aluminium sheet 1 mm, 1,020 x 47 before folding.

**How to make it.**

1. Cut the blank 1,020 x 47 and fold 16 up along one long edge: a 30 flange and a 16 upstand.
2. Drill 17 mm through the flange 880 from its west end, 17 from the back of the upstand. This lines up with the plate's drain hole.

**How it fits the parts next to it.**

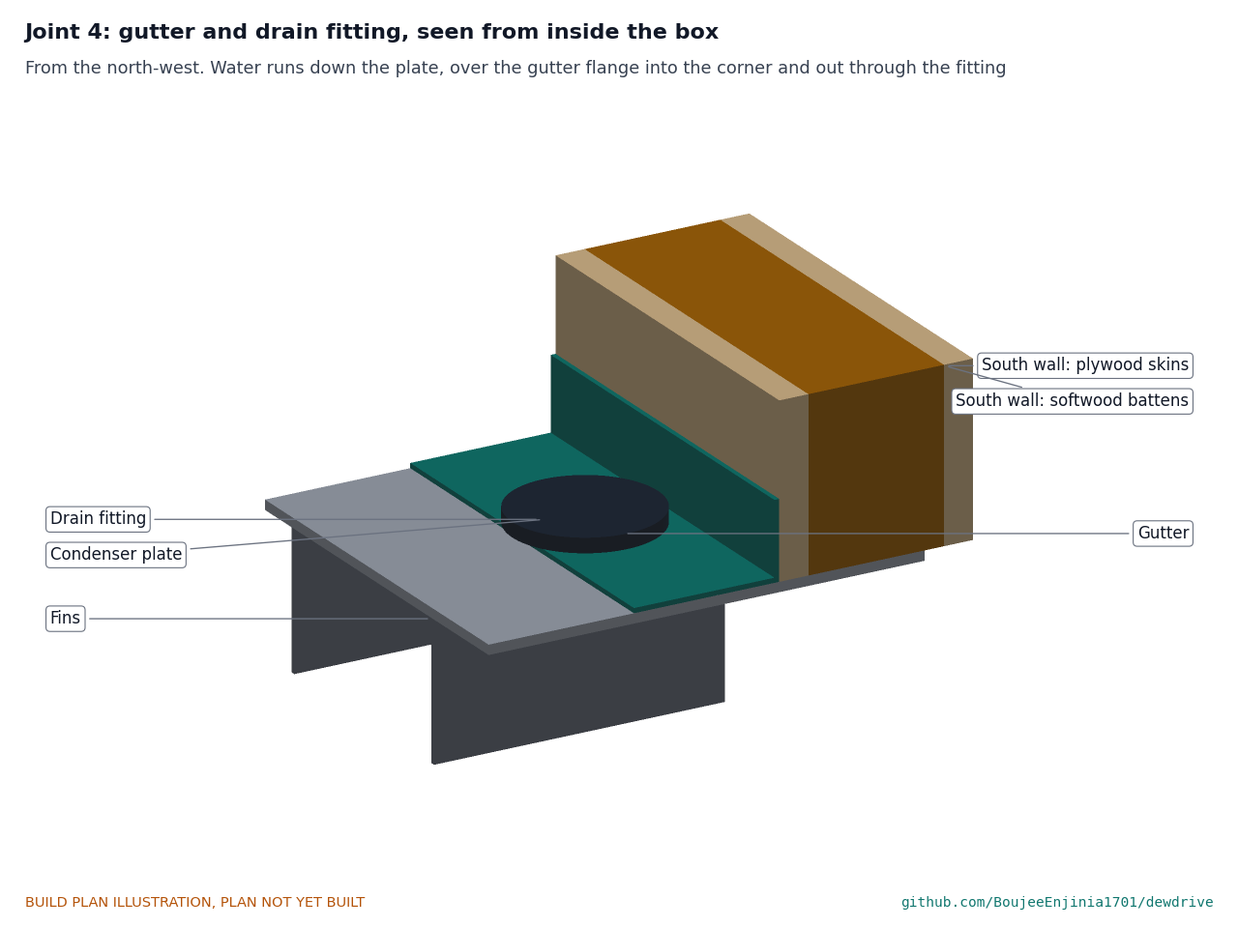
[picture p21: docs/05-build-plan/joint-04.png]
Figure 10. Making the drain path: the gutter and fitting in place


*Figure 10. Joint 4: water runs down the plate into the gutter corner and out through the fitting.*

The flange lies flat on the plate and the upstand against the south wall, both bedded in food-grade silicone, with the ends sealed to the east and west walls. Water running down the plate passes over the flange's 1 mm edge into the corner. The fitting goes down through the gutter and the plate with its sealing washer on top, nut underneath, between two fins.

**Check before moving on.** No light shows under the flange once bedded; the fitting's nut turns without touching a fin.

### 3.4 Wall ledges (make 2)

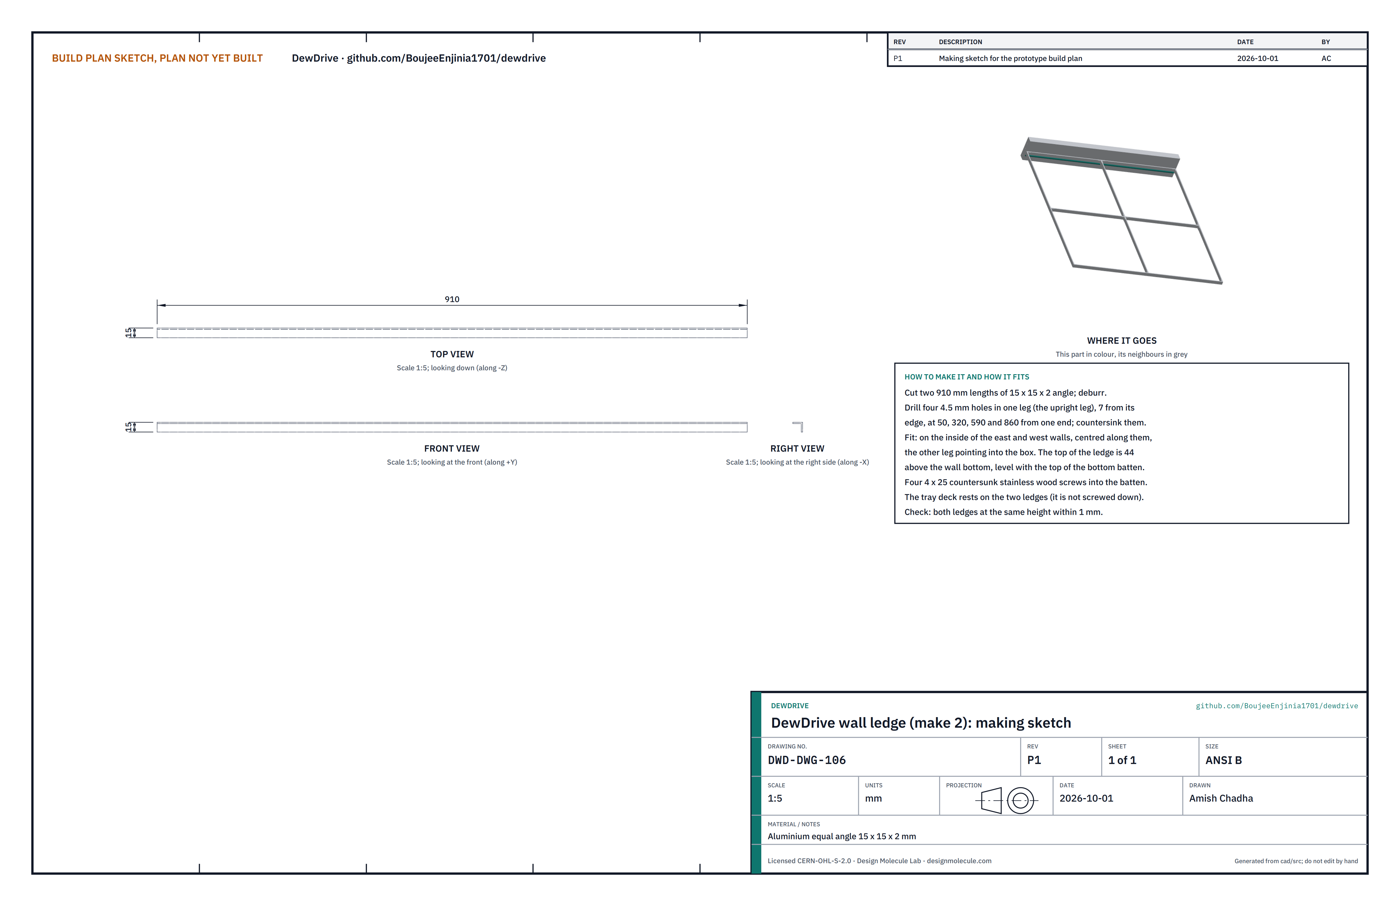
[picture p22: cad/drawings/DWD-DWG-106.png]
Figure 11. Making sketch of a wall ledge


*Figure 11. Wall ledge (DWD-DWG-106).*

**What it is and what it is made from.** Two short shelves that carry the tray deck along the east and west walls. Aluminium equal angle 15 x 15 x 2.

**How to make it.**

1. Cut two 910 lengths and deburr.
2. Drill four 4.5 mm holes in one leg, 7 from its edge, at 50, 320, 590 and 860 from one end; countersink them.

**How it fits the parts next to it.** The drilled leg lies against the inside of the east (or west) wall, centred along it, with the other leg pointing into the box. The top of the ledge is 44 above the wall bottom, level with the top of the bottom batten; four 4 x 25 countersunk stainless wood screws go into the batten (Figure 14). The deck rests on the ledges and is not screwed down.

**Check before moving on.** Both ledges are level with each other within 1 mm.

### 3.5 Tray deck frame and sealing baffle

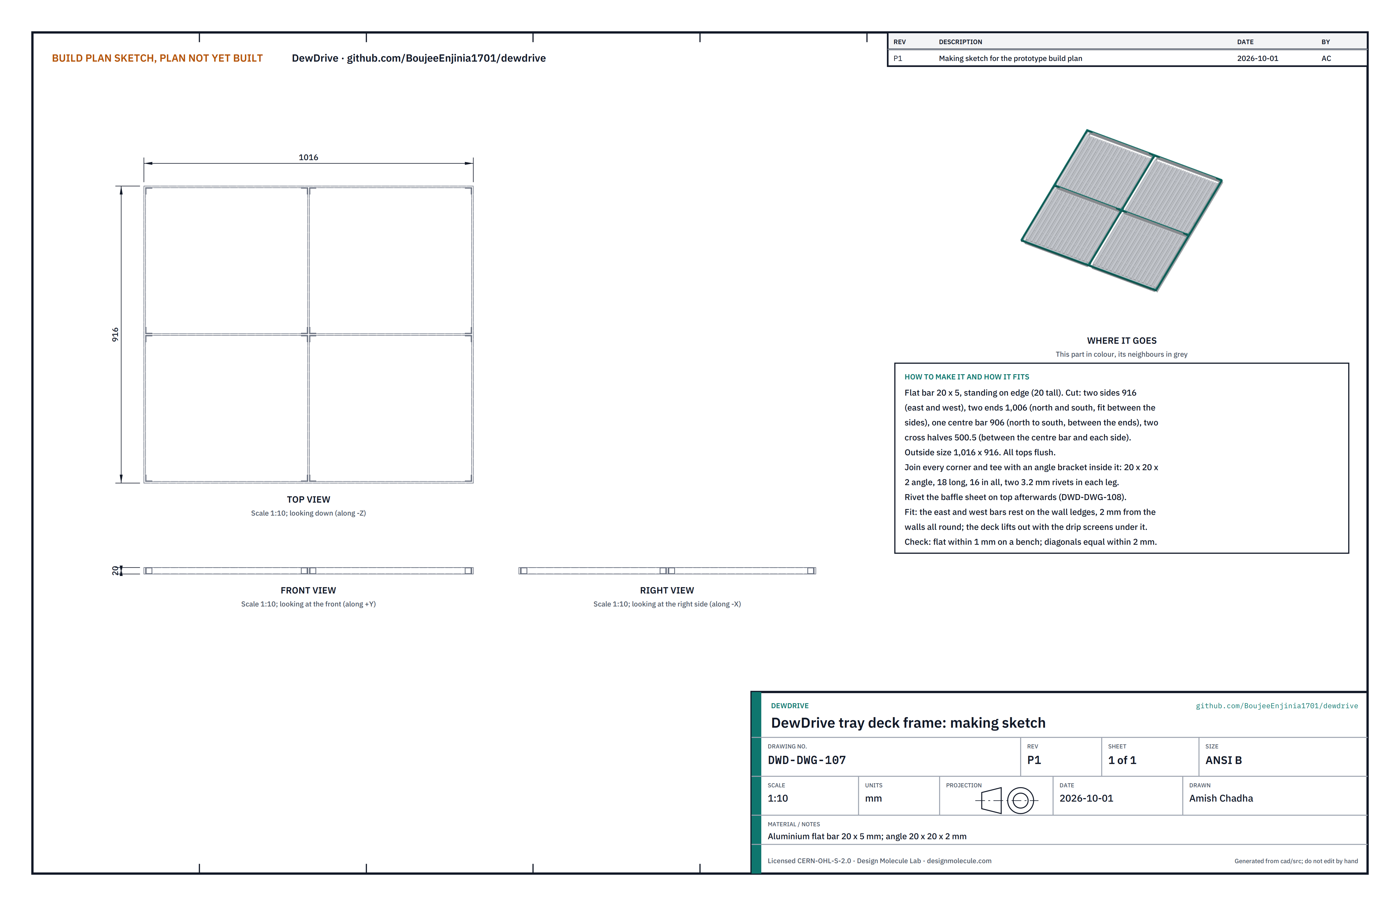
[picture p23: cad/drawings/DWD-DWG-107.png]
Figure 12. Making sketch of the deck frame


*Figure 12. Tray deck frame (DWD-DWG-107).*

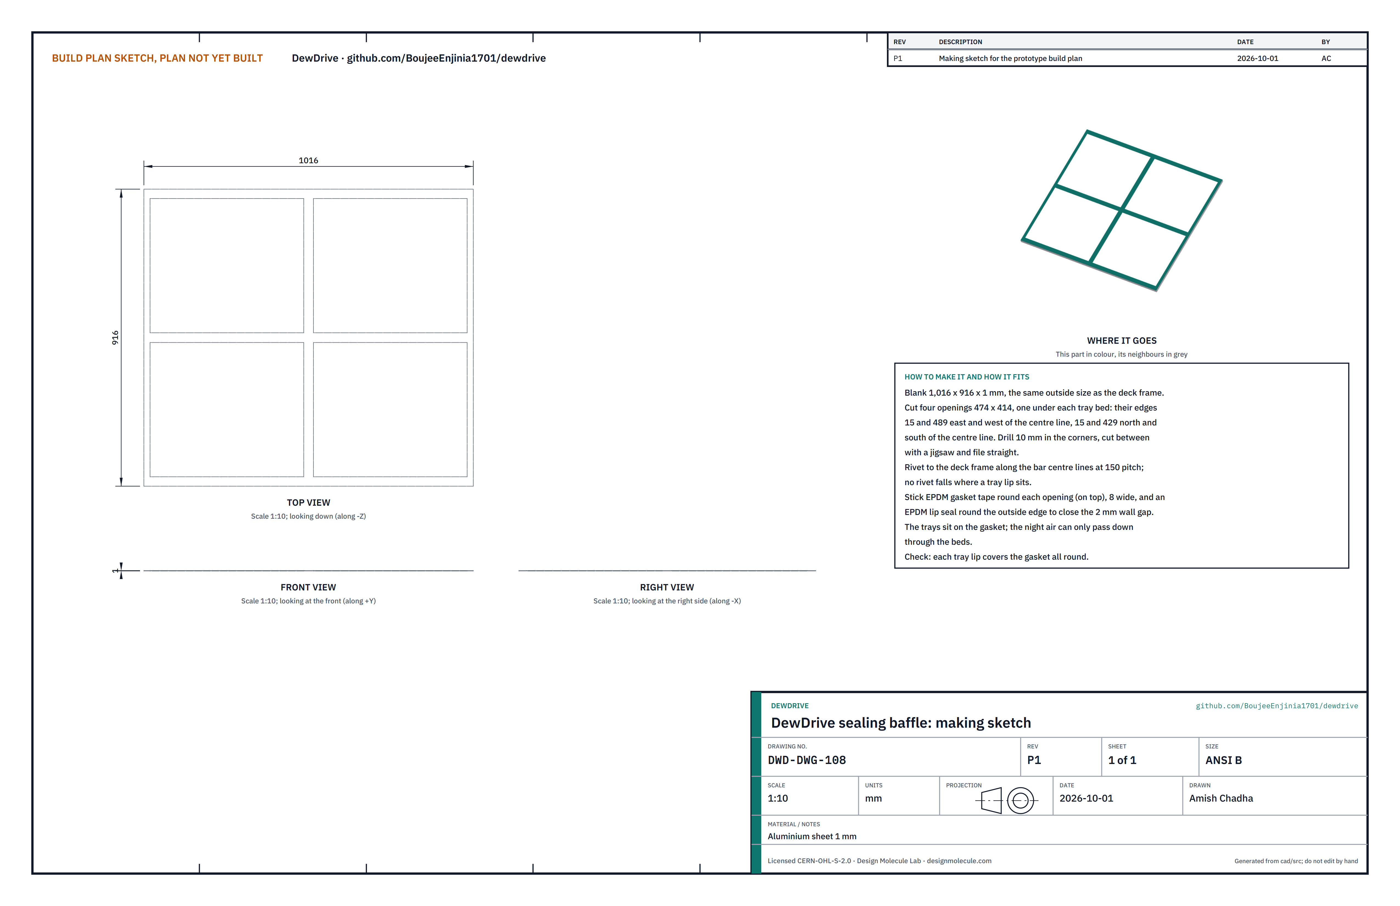
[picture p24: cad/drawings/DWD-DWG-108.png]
Figure 13. Making sketch of the sealing baffle


*Figure 13. Sealing baffle (DWD-DWG-108).*

**What it is and what it is made from.** A rigid tray that carries the four sorbent trays and seals the space above them from the space below, so the night air can only pass down through the beds. Frame: aluminium flat bar 20 x 5 on edge, joined with 16 small brackets of 20 x 20 x 2 angle. Baffle: aluminium sheet 1 mm.

**How to make it.**

1. Cut the bars: two sides 916 (east and west), two ends 1,006 (north and south, fitted between the sides), one centre bar 906 (north to south, between the ends) and two cross halves 500.5 (from the centre bar to each side). Outside size 1,016 x 916, all tops flush.
2. Cut 16 brackets 18 long from 20 x 20 x 2 angle. Clamp each joint square on a flat bench, put a bracket in its inside corner and rivet it with two 3.2 mm rivets in each leg.
3. Cut the baffle 1,016 x 916. Cut four openings 474 x 414, one under each tray bed: their edges 15 and 489 east and west of the centre line, 15 and 429 north and south of it. Drill 10 mm in the corners and cut between with a jigsaw.
4. Lay the baffle on the frame and rivet it along the bar centre lines at 150 pitch. No rivet falls where a tray lip sits.
5. Stick 8 mm EPDM gasket tape round each opening on top, and a self-adhesive EPDM lip seal round the baffle's outside edge.

**How it fits the parts next to it.**

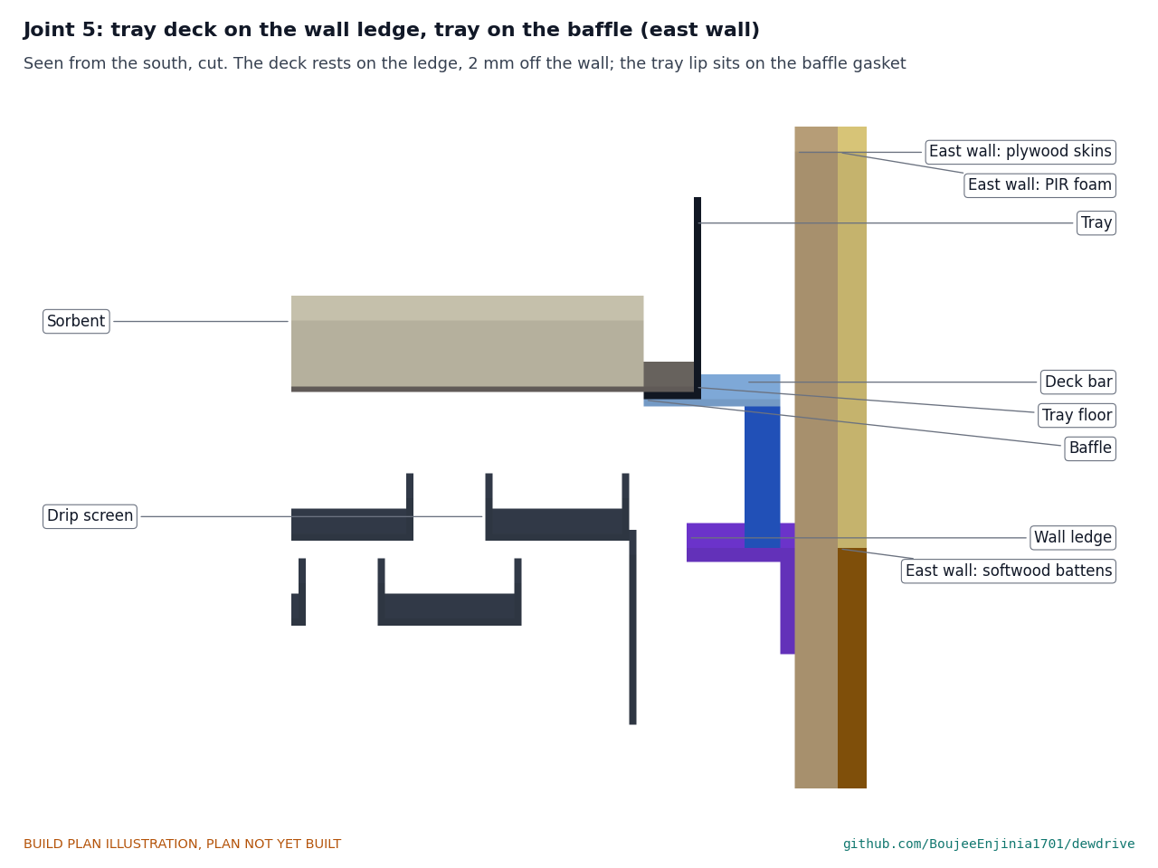
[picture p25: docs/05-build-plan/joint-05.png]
Figure 14. Joint 5: deck on the ledge, tray on the baffle


*Figure 14. The deck's side bar rests on the ledge, 2 mm off the wall; the tray lip sits on the gasket round its opening.*

The east and west bars rest on the ledges. The lip seal closes the 2 mm gap to the walls all round. The drip screens hang under the deck (section 3.6) and lift out with it.

**Check before moving on.** On a flat bench the deck rocks less than 1 mm; its diagonals are equal within 2 mm.

### 3.6 Drip screens (make 4)

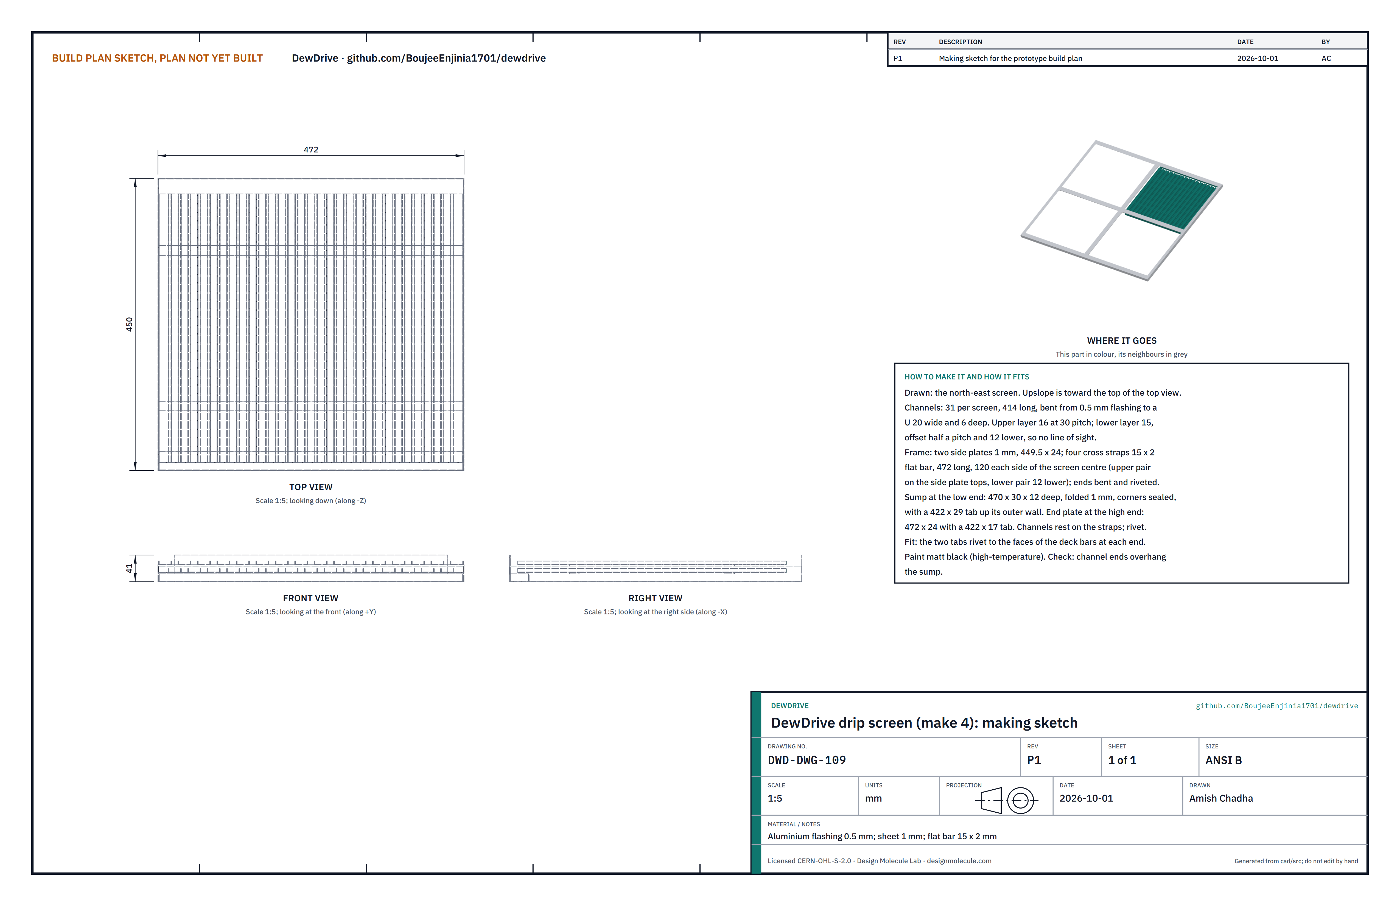
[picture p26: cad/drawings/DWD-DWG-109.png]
Figure 15. Making sketch of a drip screen


*Figure 15. Drip screen (DWD-DWG-109), the north-east one.*

**What it is and what it is made from.** A black louvre under each tray that catches any brine dripping from the bed and stops the hot bed radiating straight onto the condenser. Channels from 0.5 mm aluminium flashing; side plates, sump and end plate from 1 mm aluminium sheet; cross straps from 15 x 2 flat bar.

**How to make it.**

1. Bend 31 channels per screen from flashing, each 414 long, to a U 20 wide and 6 deep (a bending brake or two hardwood battens in a vice).
2. Cut two side plates 449.5 x 24 and four cross straps 472 long. Bend 10 at each strap end down 90°. Rivet the upper pair of straps on the side plate tops and the lower pair 12 lower between the plates, 120 each side of the screen's centre.
3. Fold the sump, 470 x 30 x 12 deep, with a tab 422 x 29 rising from its outer (low) wall; seal its corners with silicone. Fold the end plate, 472 x 24, with a tab 422 x 17. Rivet the sump between the side plates at the low end and the end plate at the high end.
4. Lay 16 channels on the upper straps at 30 pitch and 15 on the lower straps, offset half a pitch, all with their low ends over the sump; rivet each to its straps.
5. Paint the whole screen matt black with high-temperature paint.

**How it fits the parts next to it.**

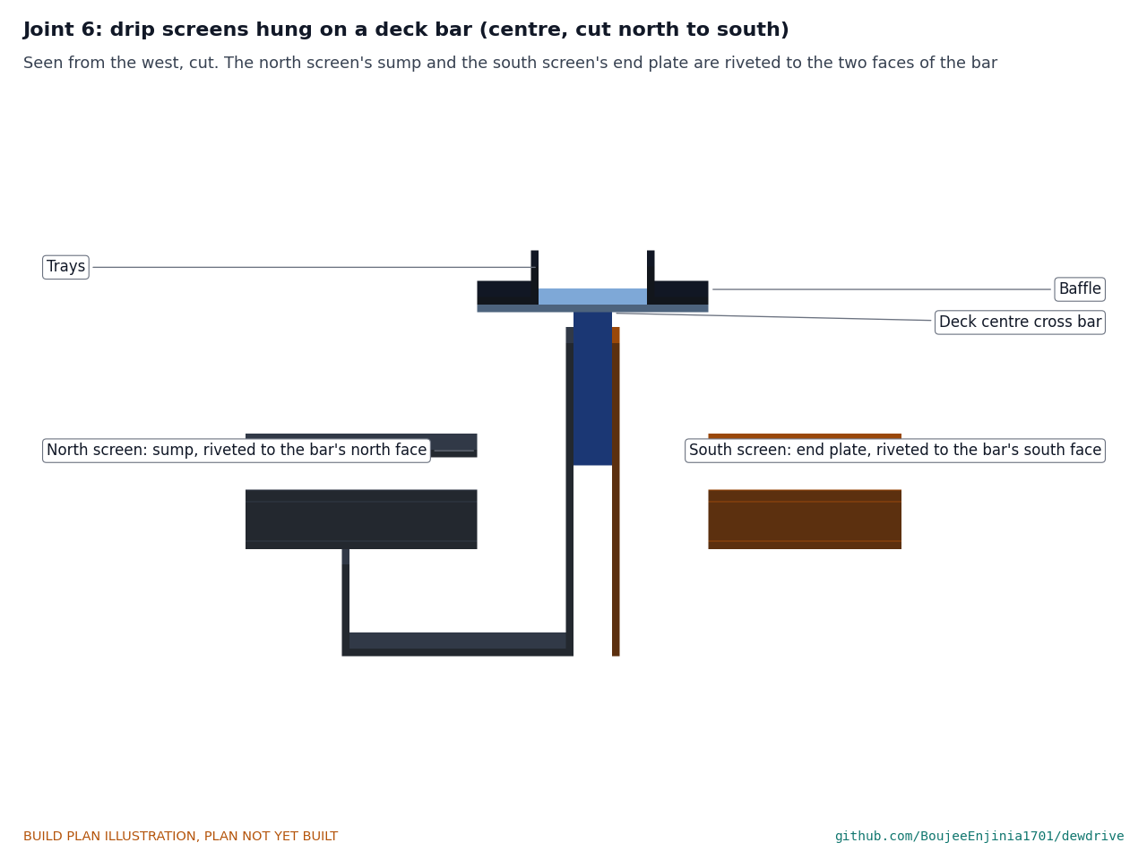
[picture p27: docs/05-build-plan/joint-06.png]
Figure 16. Joint 6: the screens hung on the deck's centre cross bar


*Figure 16. The north screen's sump tab and the south screen's end plate tab are riveted to the two faces of the deck's cross bar.*

Each screen hangs under its opening by two tabs: the sump tab riveted to the face of the deck bar at its low (south) end, the end plate tab to the bar at its high end. Rivet them with the deck upside down on the bench (step 7). Nothing touches the condenser or the gutter: the sumps sit about 7 above the gutter's top edge.

**Check before moving on.** Looking straight down through each opening, no part of the floor below shows between the channels; every channel end overhangs its sump.

### 3.7 Sorbent trays (make 4)

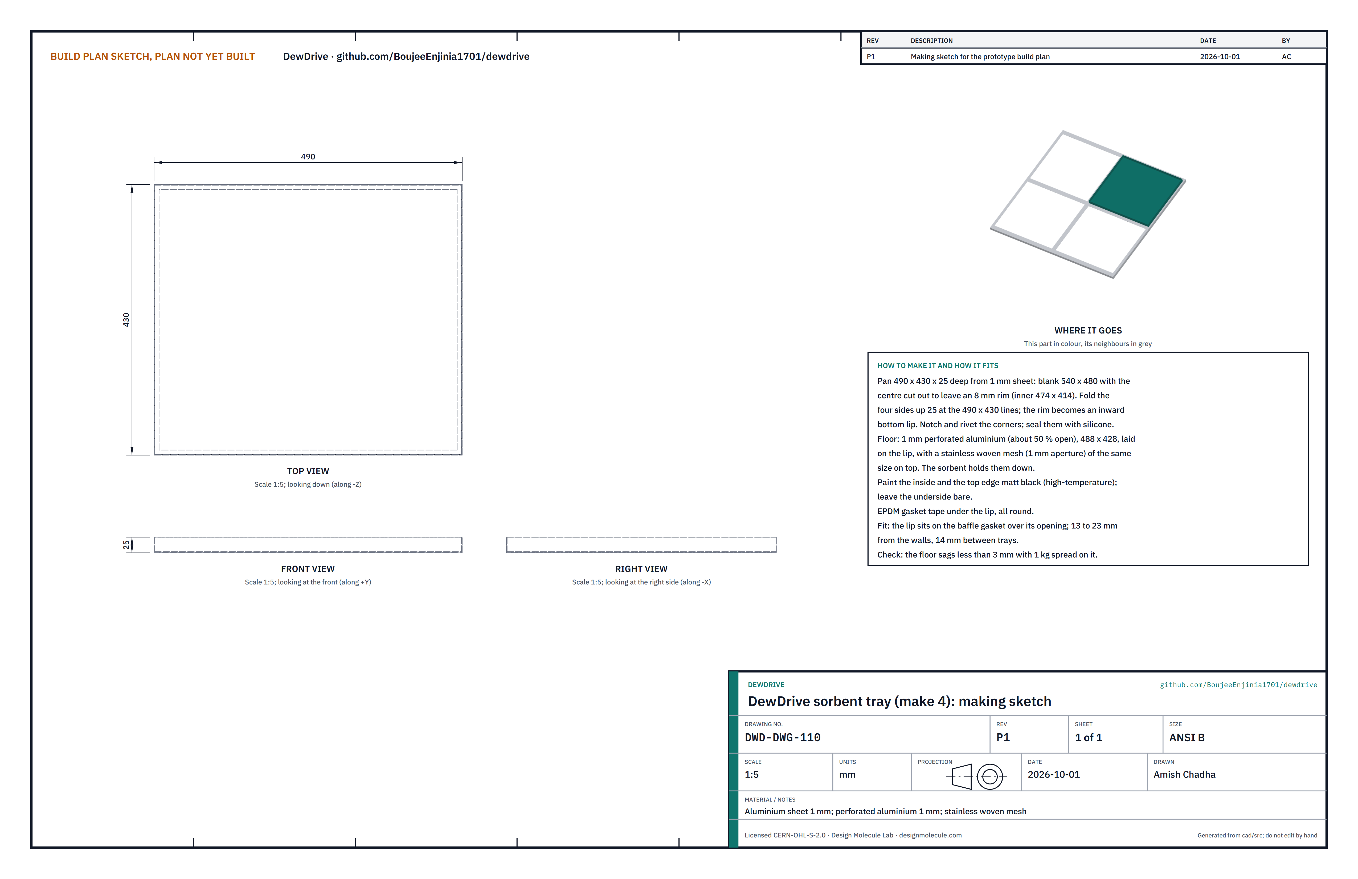
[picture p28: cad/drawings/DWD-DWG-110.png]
Figure 17. Making sketch of a tray


*Figure 17. Sorbent tray (DWD-DWG-110).*

**What it is and what it is made from.** Shallow black pans that hold the sorbent, with a floor that lets air through. Pan: aluminium sheet 1 mm. Floor: 1 mm perforated aluminium, about 50 % open, with a fine stainless woven mesh (1 mm aperture) on top.

**How to make it.**

1. Cut a blank 540 x 480 and cut out its centre to leave an 8 mm rim: inner 474 x 414.
2. Fold the four sides up 25 on the 490 x 430 lines; the rim becomes an inward bottom lip. Notch the corners, rivet the overlaps and seal them with silicone.
3. Paint the inside and the top edge matt black (high-temperature); leave the underside bare.
4. Cut the perforated sheet and the mesh 488 x 428 and lay them on the lip, mesh on top.
5. Stick EPDM gasket tape under the lip, all round.

**How it fits the parts next to it.** The tray's lip sits on the gasket round its opening in the baffle (Figure 14), 13 to 23 from the walls and 14 from the next tray. The tray is lifted out by its sides.

**Check before moving on.** With 1 kg spread on the floor, the floor sags less than 3 mm.

### 3.8 Composite sorbent

**What it is and what it is made from.** About 4 kg of silica gel beads holding calcium chloride in their pores: 3.0 kg of mesoporous silica gel beads (2 to 5 mm) and 1.0 kg of food-grade anhydrous calcium chloride, 25 % salt by mass. Figure 14 shows the bed in its tray.

**How to make it.**

1. Wear gloves and eye protection. Work in a plastic or stainless tub, outdoors or with good airflow.
2. Add the calcium chloride slowly to about 3 L of clean water, stirring; it gets hot. Let it cool.
3. Pour the cooled solution slowly over the gel while turning the beads, until the beads have taken it all up and no liquid stands in the tub. Cover and leave for 24 hours.
4. Dry the beads in thin layers at 120 to 150 °C (an oven, or the closed collector in sun) until they stop losing mass: they should then weigh about 4.0 kg.
5. Spread 1.0 kg evenly in each tray: about 9 mm deep.

**How it fits the parts next to it.** It lies loose on the tray's mesh floor.

**Check before moving on.** Total mass 4.0 kg, give or take 0.1 kg, after drying; no wet or caked beads.

### 3.9 Lid

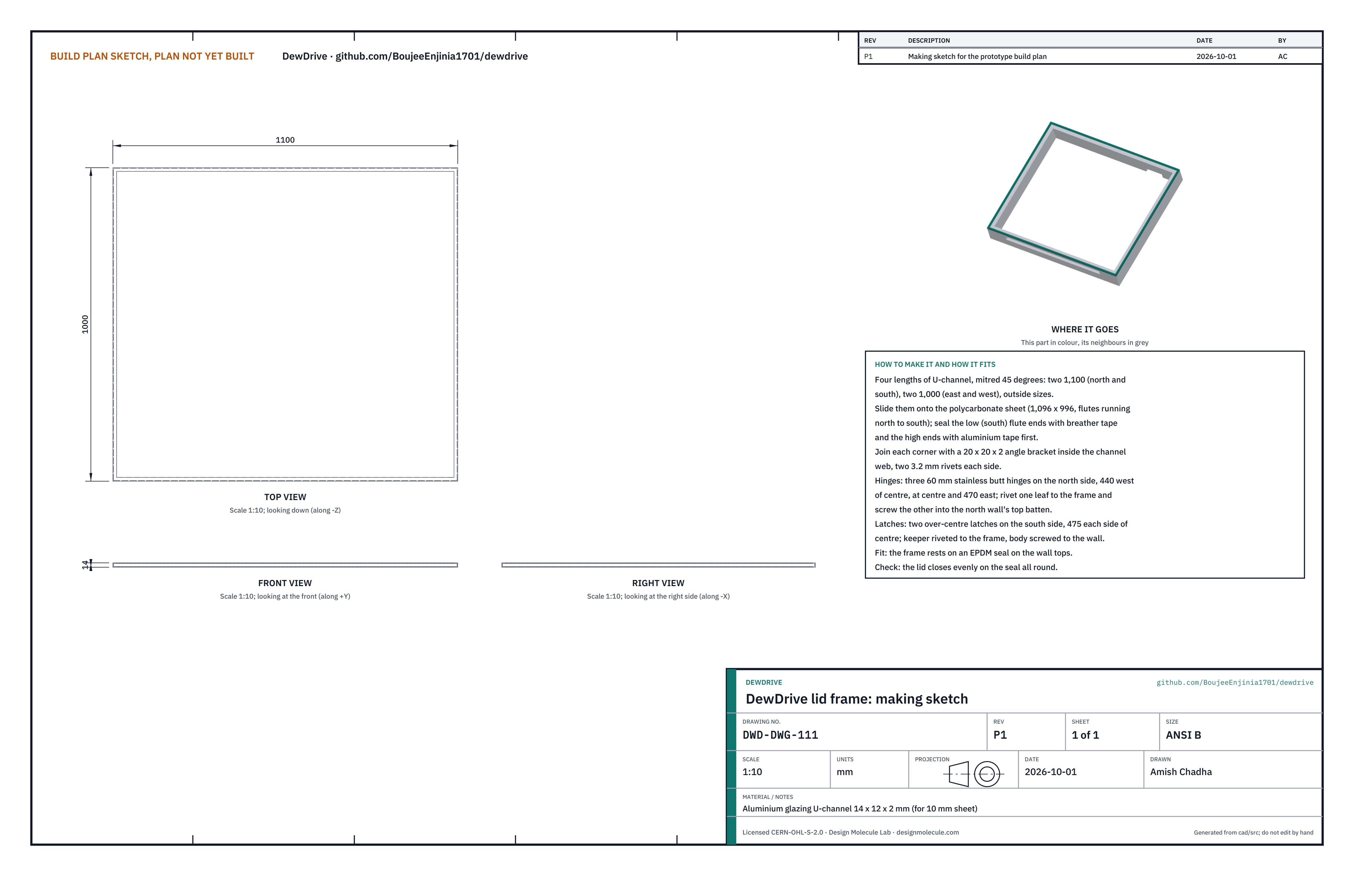
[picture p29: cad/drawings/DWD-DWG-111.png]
Figure 18. Making sketch of the lid frame


*Figure 18. Lid frame (DWD-DWG-111).*

**What it is and what it is made from.** The glazing: a 10 mm twin-wall polycarbonate sheet, 1,096 x 996, rated 130 °C or more, held in an aluminium glazing U-channel frame (14 x 12 x 2, for 10 mm sheet).

**How to make it.**

1. Cut the four channel lengths with 45° mitres: two 1,100 and two 1,000 (outside sizes).
2. Tape the sheet's flute ends: breather tape on the low (south) edge, aluminium tape on the high (north) edge. The flutes run north to south.
3. Slide the channels onto the sheet. Join each corner with a 20 x 20 x 2 angle bracket inside the channel web, two 3.2 mm rivets each side.
4. Rivet one leaf of each of three 60 mm stainless butt hinges to the north side of the frame, 440 west of centre, at centre and 470 east. Rivet the keepers of two over-centre latches to the south side, 475 each side of centre.

**How it fits the parts next to it.**

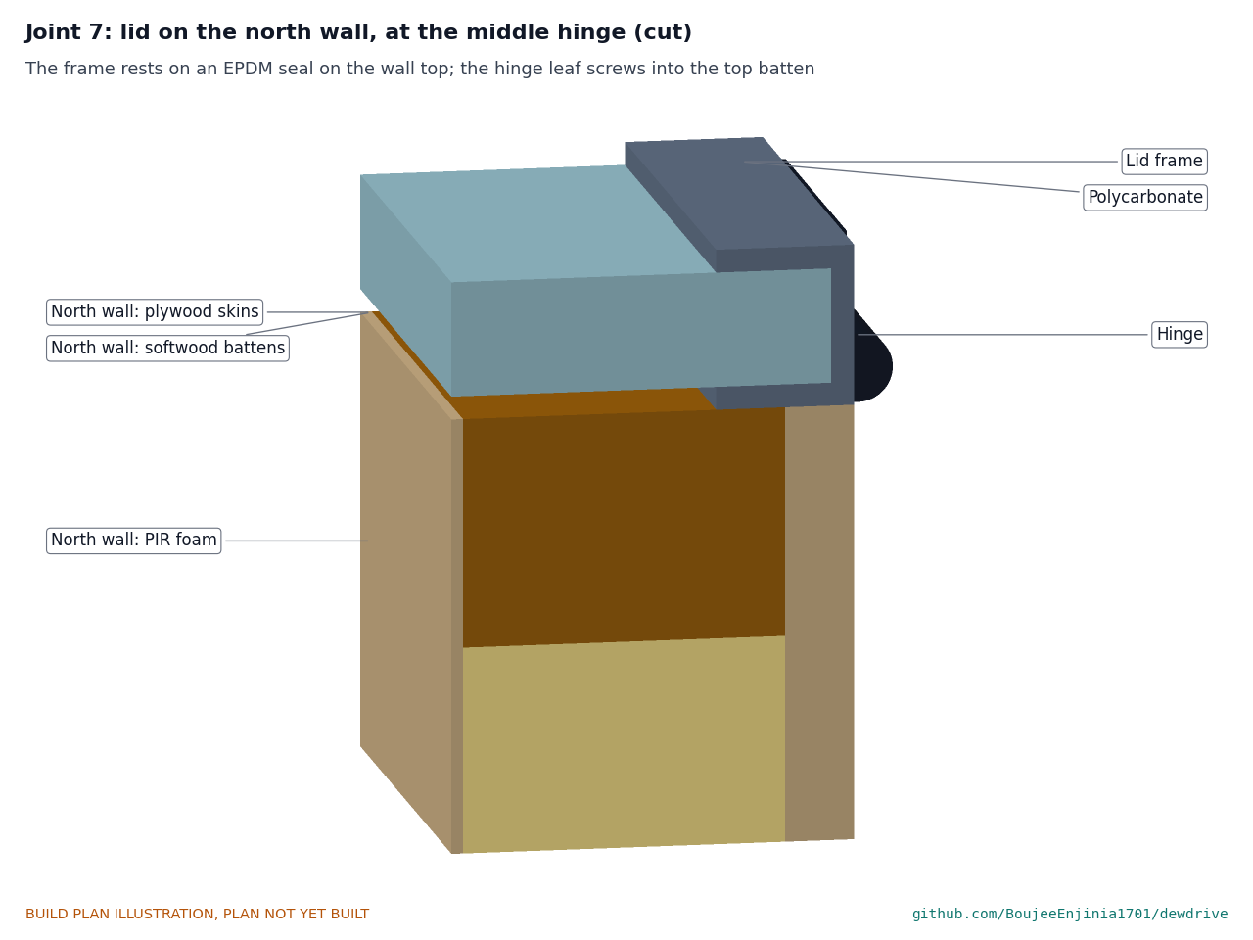
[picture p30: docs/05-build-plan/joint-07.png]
Figure 19. Joint 7: the lid on the north wall at the middle hinge


*Figure 19. The frame rests on an EPDM seal on the wall top; the hinge leaf screws into the top batten.*

The frame rests on a self-adhesive EPDM seal along the wall tops. The hinges' other leaves screw into the north wall's top batten; the latch bodies screw to the south wall. The fan hood sits between two hinges (Figure 22).

**Check before moving on.** Latched, the lid presses evenly on the seal all round; a strip of paper is gripped everywhere.

### 3.10 Inlet flap

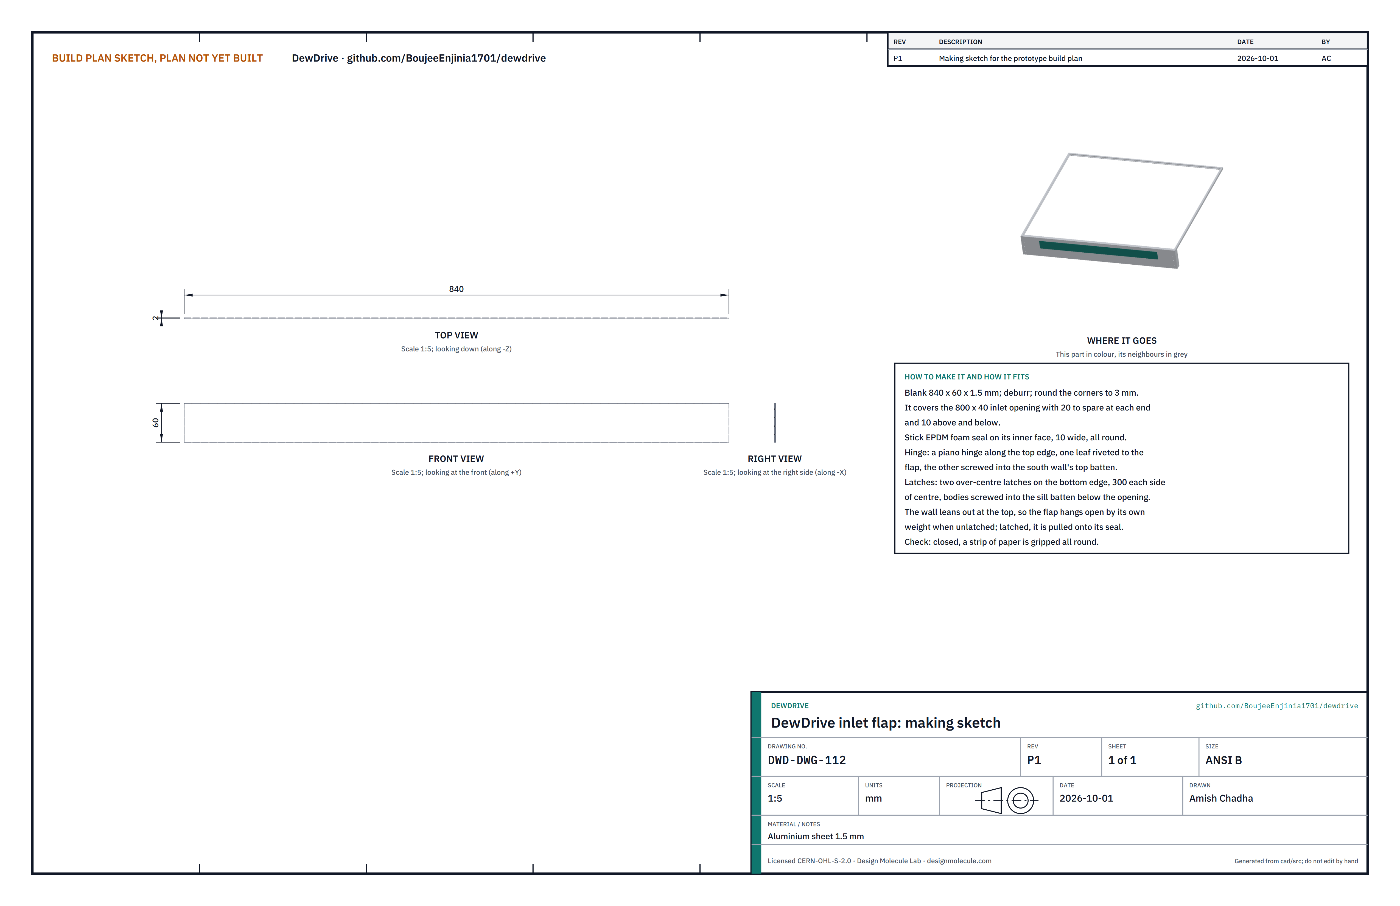
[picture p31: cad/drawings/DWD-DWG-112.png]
Figure 20. Making sketch of the inlet flap


*Figure 20. Inlet flap (DWD-DWG-112).*

**What it is and what it is made from.** The flap that closes the inlet opening by day. Aluminium sheet 1.5 mm, 840 x 60.

**How to make it.**

1. Cut the blank, deburr and round the corners to 3.
2. Stick 10 mm EPDM foam seal on its inner face, all round.
3. Rivet one leaf of an 840 mm piano hinge along the top edge.

**How it fits the parts next to it.**

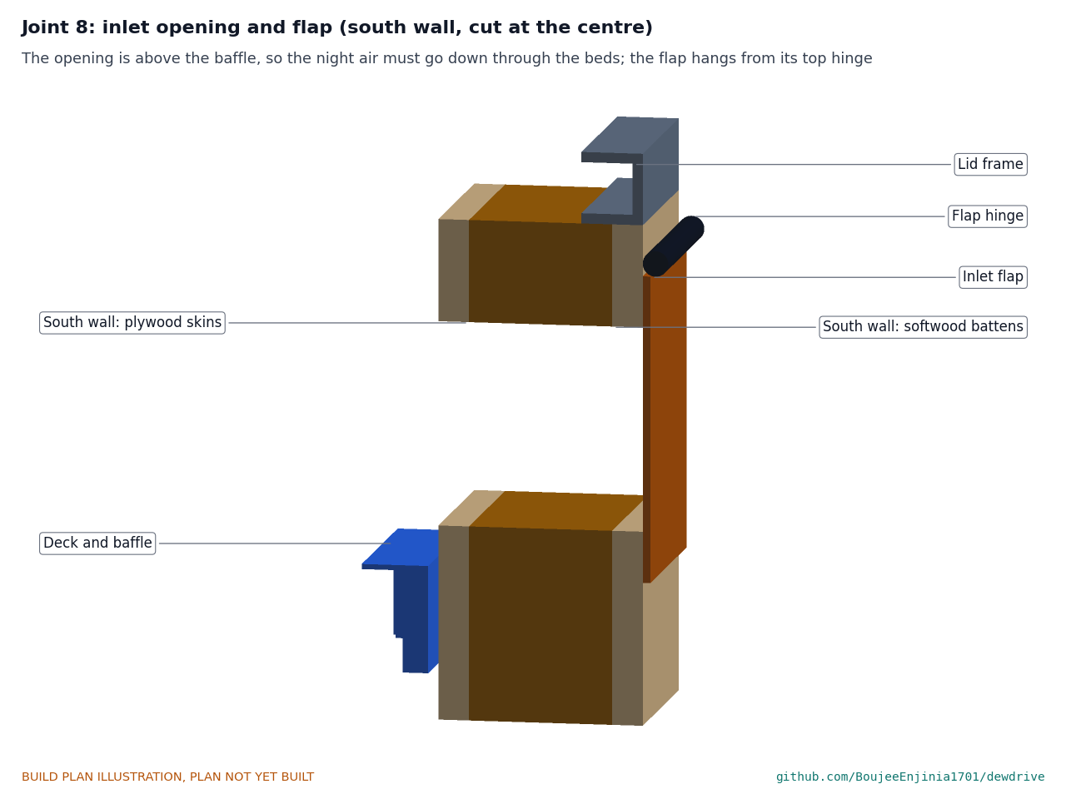
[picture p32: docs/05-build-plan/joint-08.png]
Figure 21. Joint 8: the inlet opening and flap


*Figure 21. The opening is above the deck, so the night air must go down through the beds; the flap hangs from its top hinge.*

The hinge's other leaf screws into the south wall's top batten, so the flap covers the opening with 20 to spare at each end and 10 above and below. Two over-centre latches at its bottom edge, 300 each side of centre, have their bodies screwed into the sill batten. The wall leans out at the top, so the flap hangs open by its own weight when unlatched.

**Check before moving on.** Latched, a strip of paper is gripped all round the seal.

### 3.11 Fan hood and outlet flap

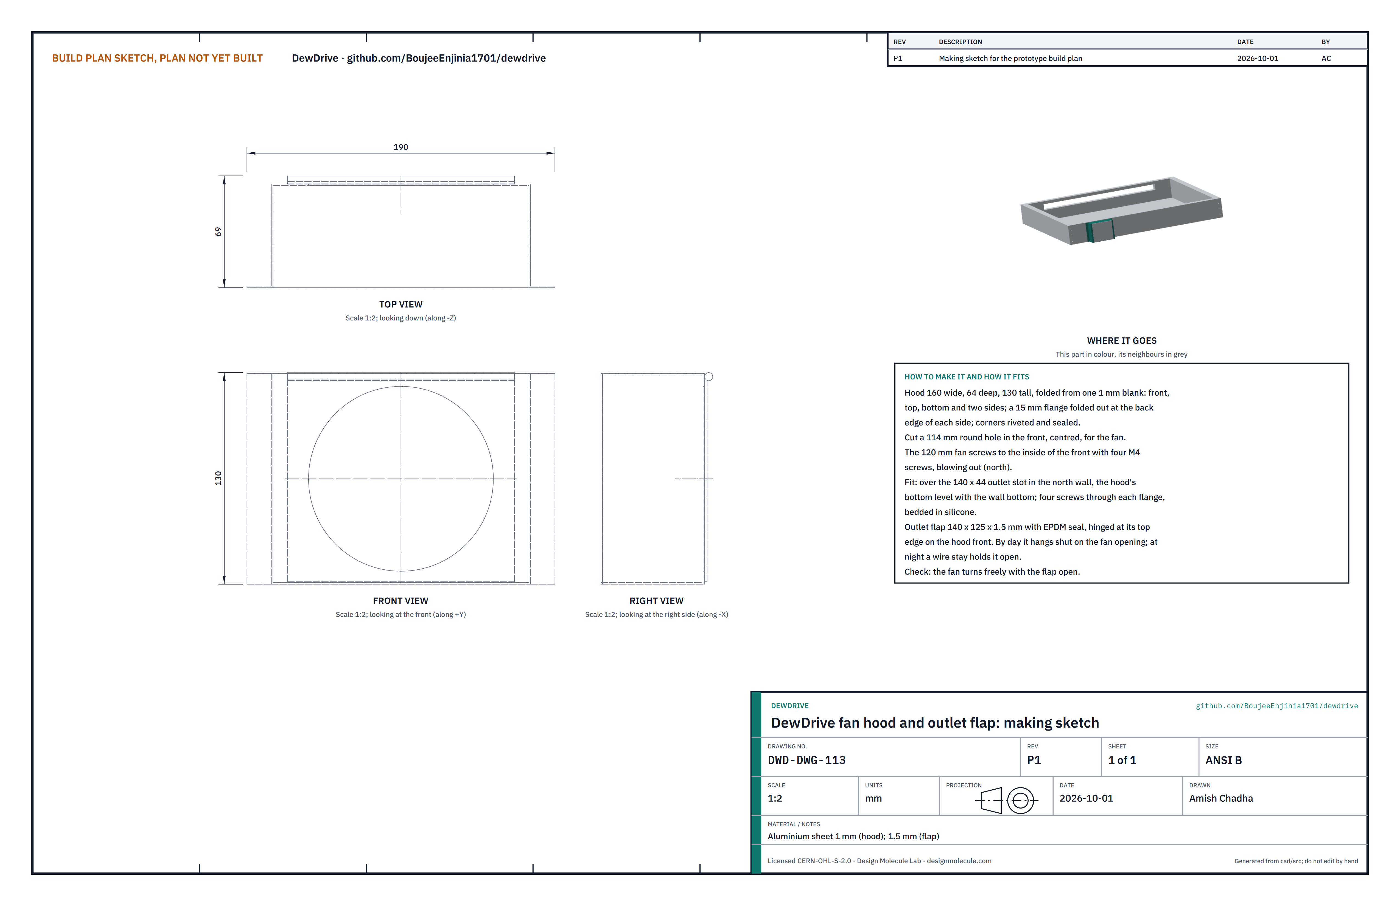
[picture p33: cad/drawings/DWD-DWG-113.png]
Figure 22. Making sketch of the fan hood and outlet flap


*Figure 22. Fan hood and outlet flap (DWD-DWG-113).*

**What it is and what it is made from.** A sheet-metal box on the outside of the north wall over the outlet slot. It holds the night fan; a flap closes the fan opening by day. Hood: aluminium sheet 1 mm. Flap: aluminium sheet 1.5 mm, 140 x 125.

**How to make it.**

1. Fold the hood from one blank: front, top, bottom and two sides, 160 wide, 64 deep and 130 tall, with a 15 mm flange folded out at the back edge of each side. Rivet and seal the corners.
2. Cut a 114 mm round hole in the front, centred.
3. Screw the 120 mm fan to the inside of the front with four M4 screws, blowing outward.
4. Stick EPDM seal round the flap's inner face and fit a small hinge along its top edge, riveted to the hood front above the hole. Fit a wire stay to hold it open at night and a turn button to hold it shut by day.

**How it fits the parts next to it.**

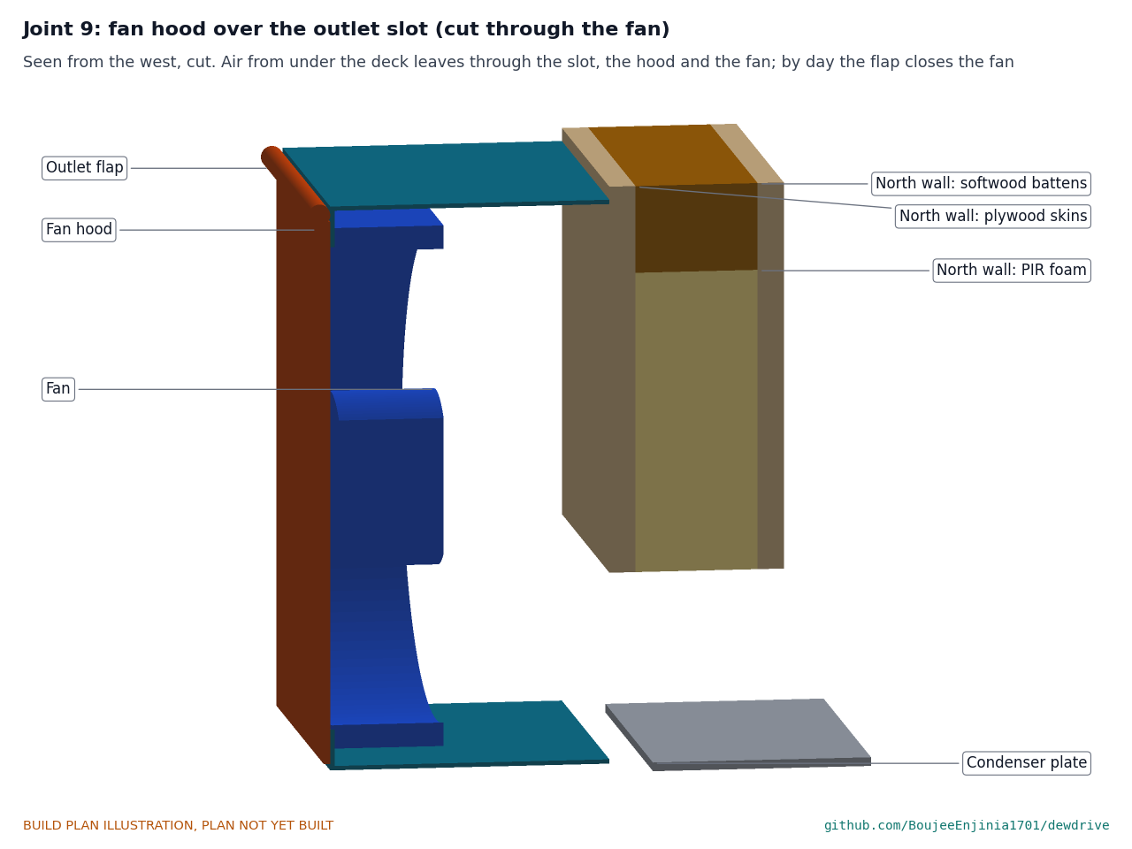
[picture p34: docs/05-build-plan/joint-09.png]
Figure 23. Joint 9: the hood over the outlet slot


*Figure 23. Air from under the deck leaves through the slot, the hood and the fan.*

The hood covers the 140 x 44 slot, its bottom level with the wall bottom, with four screws through each flange into the wall, bedded in silicone. The fan lead goes through a cable gland in the hood's bottom.

**Check before moving on.** The fan turns freely with the flap open, and the flap closes flat on its seal.

### 3.12 Stand rails (make 2)

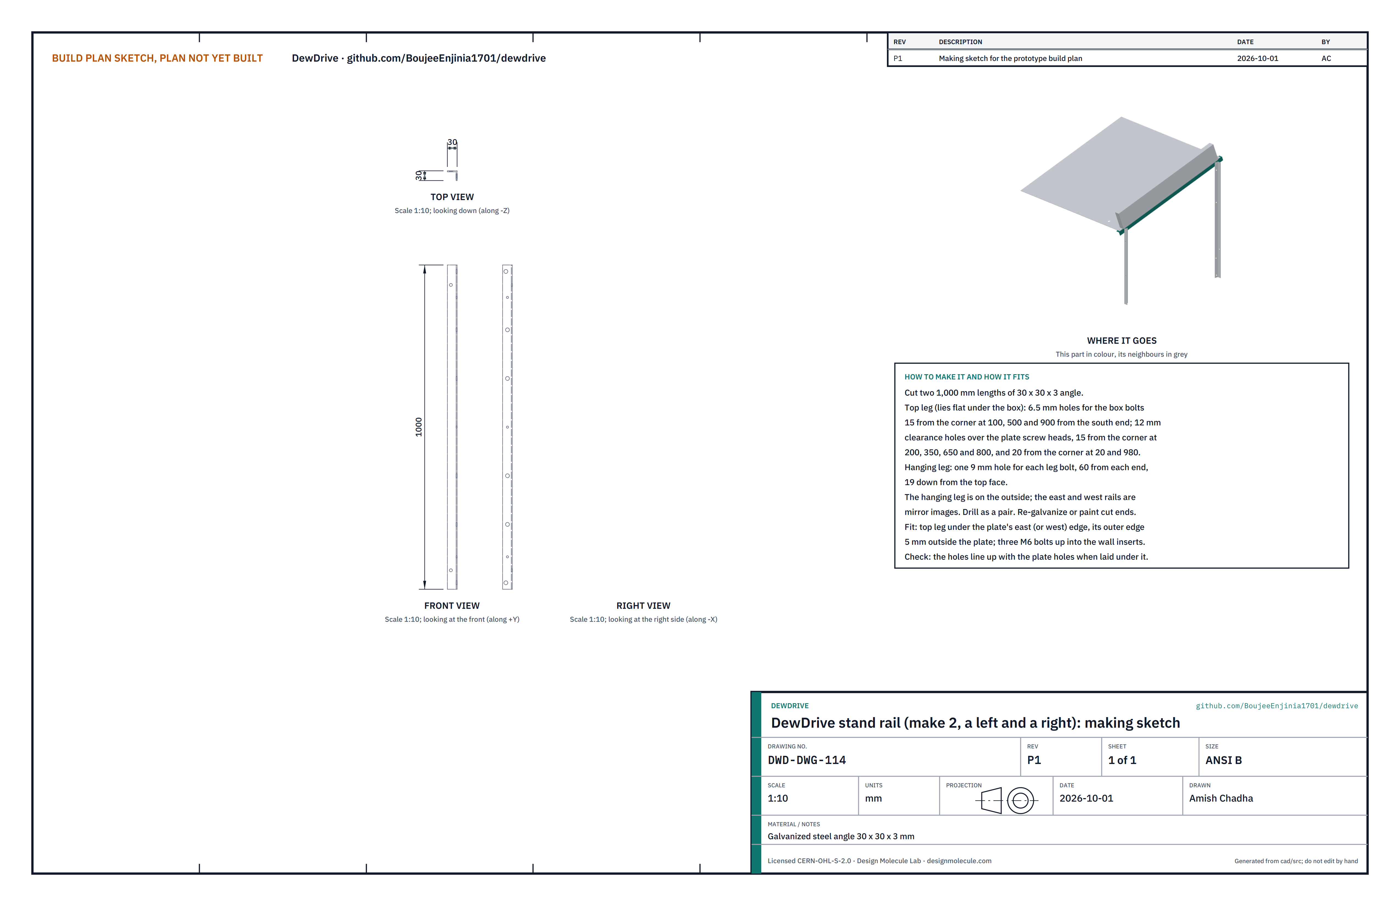
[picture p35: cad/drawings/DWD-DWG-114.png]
Figure 24. Making sketch of a rail


*Figure 24. Stand rail (DWD-DWG-114).*

**What it is and what it is made from.** The two rails the box sits on, one under each of its east and west edges. Galvanized steel angle 30 x 30 x 3, 1,000 long.

**How to make it.**

1. Cut two lengths; they are mirror images, so drill them clamped as a pair.
2. Top leg: three 6.5 mm holes, 15 from the corner, at 100, 500 and 900 from the south end; and 12 mm clearance holes over the plate screw heads, 15 from the corner at 200, 350, 650 and 800, and 20 from the corner at 20 and 980.
3. Hanging leg: one 9 mm hole 60 from each end, 19 down from the top face.
4. Paint the cut ends and holes with zinc-rich paint.

**How it fits the parts next to it.**

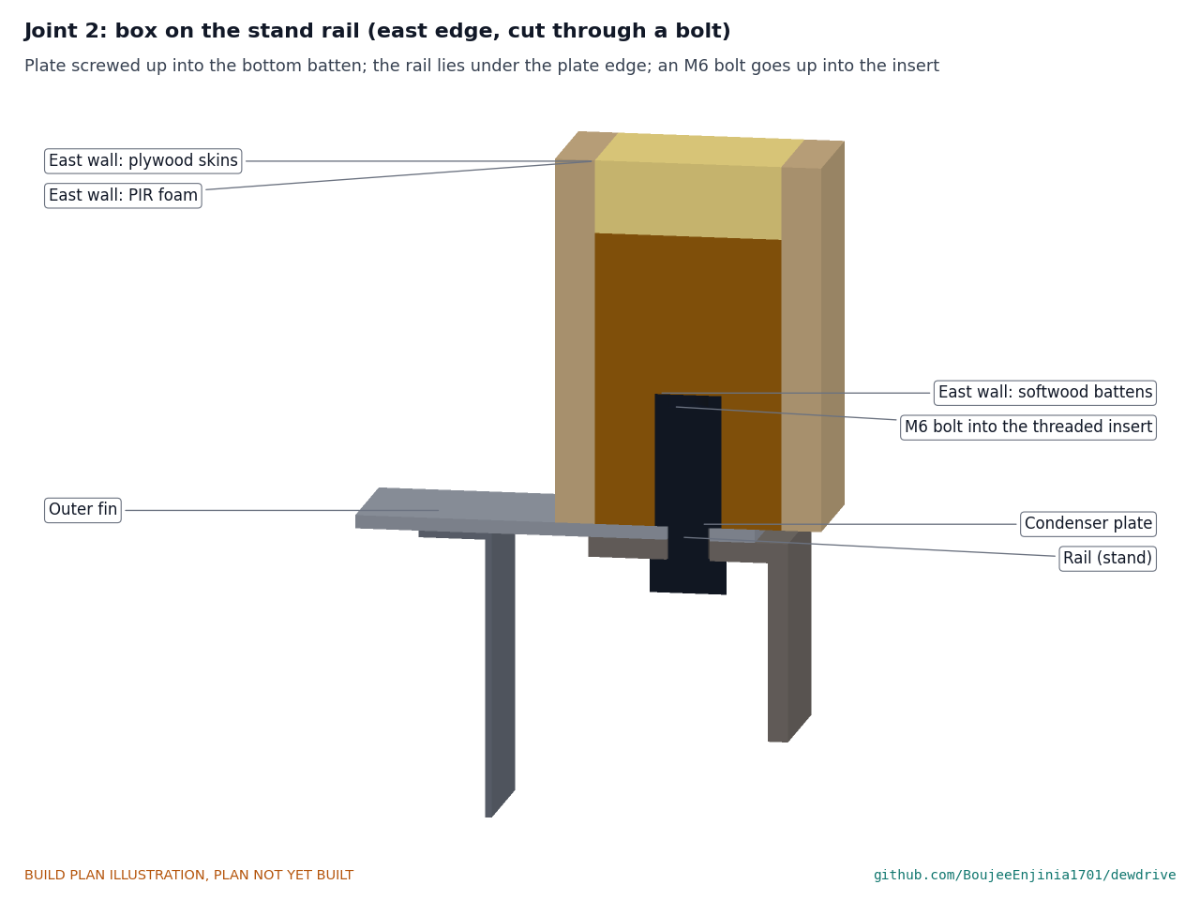
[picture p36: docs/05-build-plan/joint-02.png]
Figure 25. Joint 2: the box on the rail, cut through a bolt


*Figure 25. The rail lies under the plate edge; an M6 bolt goes up through the rail and the plate into the threaded insert.*

The top leg lies under the plate's east (or west) edge with the hanging leg outside, its outer face 5 outside the plate edge. Three M6 x 40 bolts go up into the wall inserts; the plate screw heads sit in the clearance holes.

**Check before moving on.** Laid under the plate, every rail hole lines up with its plate hole or screw head.

### 3.13 Legs (make 4: two south, two north)

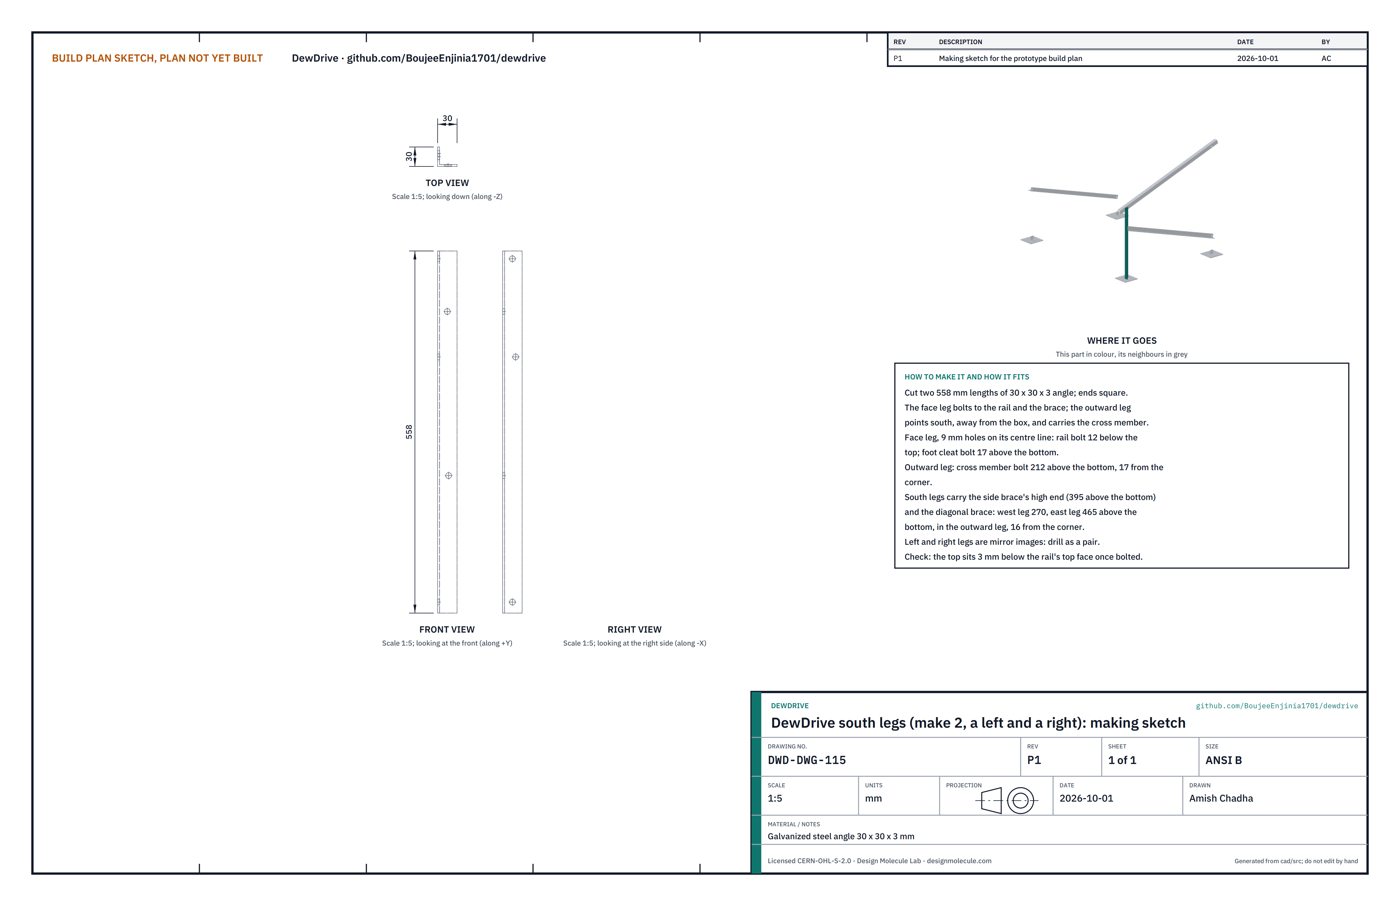
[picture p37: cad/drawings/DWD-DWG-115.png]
Figure 26. Making sketch of the south legs


*Figure 26. South legs (DWD-DWG-115).*

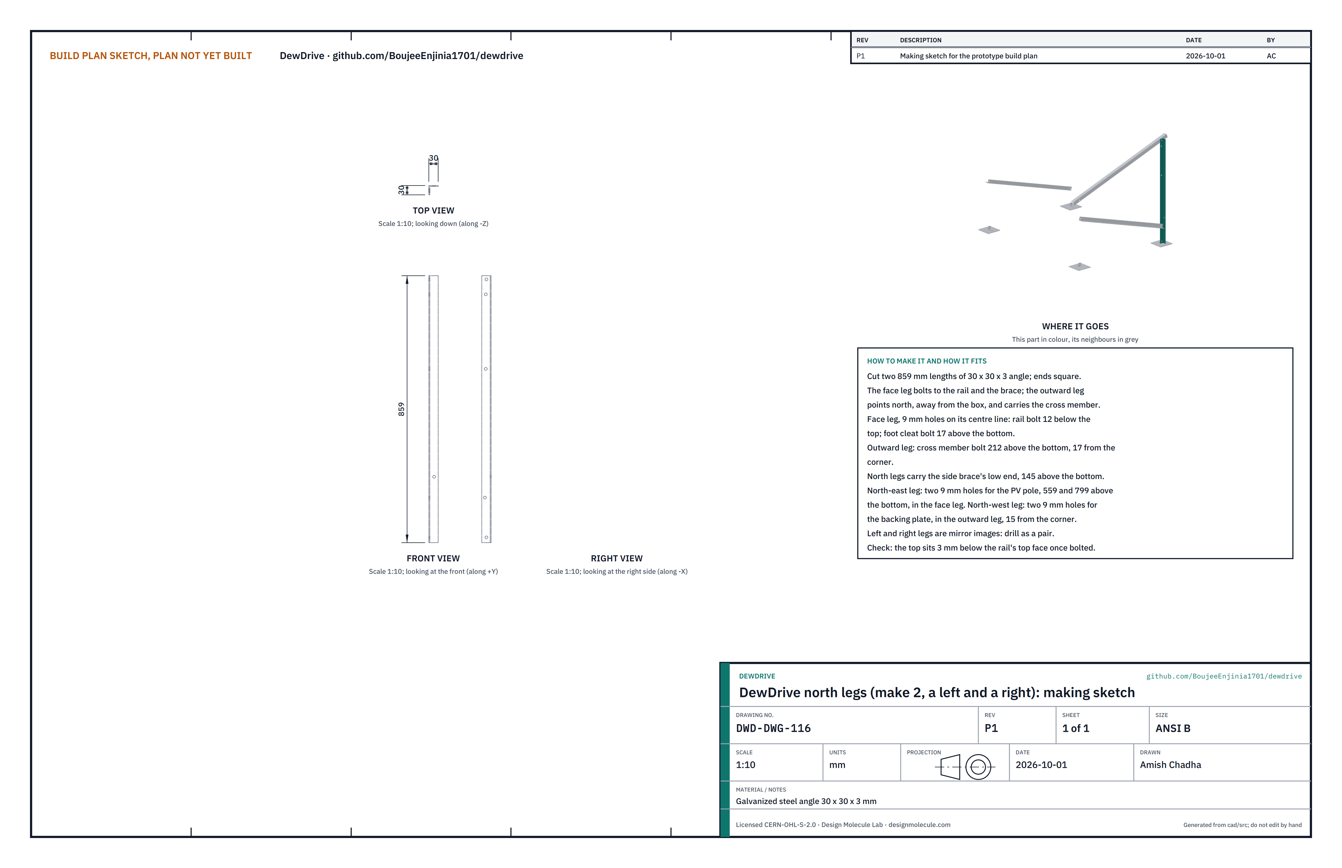
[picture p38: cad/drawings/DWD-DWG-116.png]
Figure 27. Making sketch of the north legs


*Figure 27. North legs (DWD-DWG-116).*

**What it is and what it is made from.** The four legs, short at the south and tall at the north, which give the 20° tilt. Galvanized steel angle 30 x 30 x 3: south legs 558, north legs 859.

**How to make it.**

1. Cut the four lengths with square ends. Each leg has a face leg (it bolts to the rail and the side brace) and an outward leg (it points away from the box and carries the cross member).
2. All legs, 9 mm holes: face leg, on its centre line, 12 below the top (rail bolt) and 17 above the bottom (foot cleat); outward leg, 212 above the bottom and 17 from the corner (cross member).
3. South legs: a hole in the face leg 395 above the bottom (side brace); in the outward leg, 16 from the corner, the west leg at 270 and the east leg at 465 above the bottom (diagonal brace).
4. North legs: a hole in the face leg 145 above the bottom (side brace). North-east leg: two more in the face leg, 559 and 799 above the bottom (PV pole). North-west leg: two more in the outward leg, 15 from the corner (backing plate), as DWD-DWG-122 gives.
5. Left and right legs are mirror images; drill them as pairs. Paint the holes and cut ends.

**How it fits the parts next to it.**

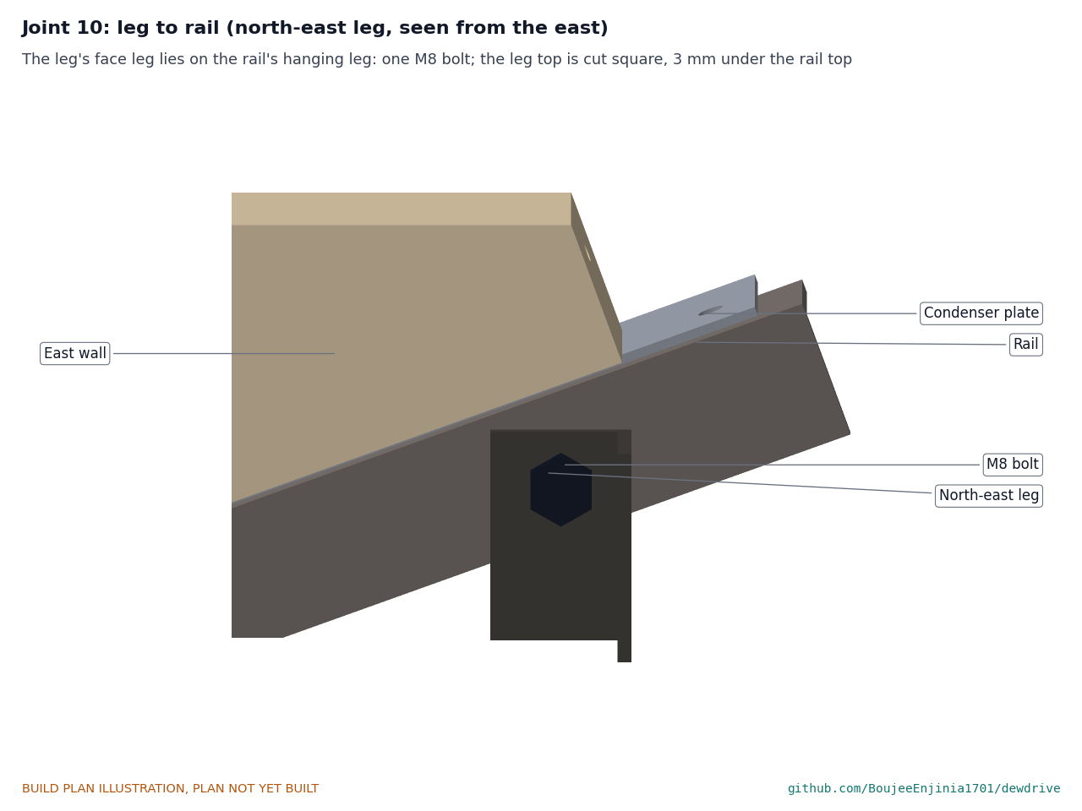
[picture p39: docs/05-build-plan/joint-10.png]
Figure 28. Joint 10: a leg on its rail


*Figure 28. The leg's face leg lies on the rail's hanging leg, held by one M8 bolt; its top is 3 below the rail's top face.*

**Check before moving on.** Bolted to its rail, each leg's top is 2 to 4 below the rail's top face and the leg stands square to the rail's line.

### 3.14 Foot plates and cleats (make 4)

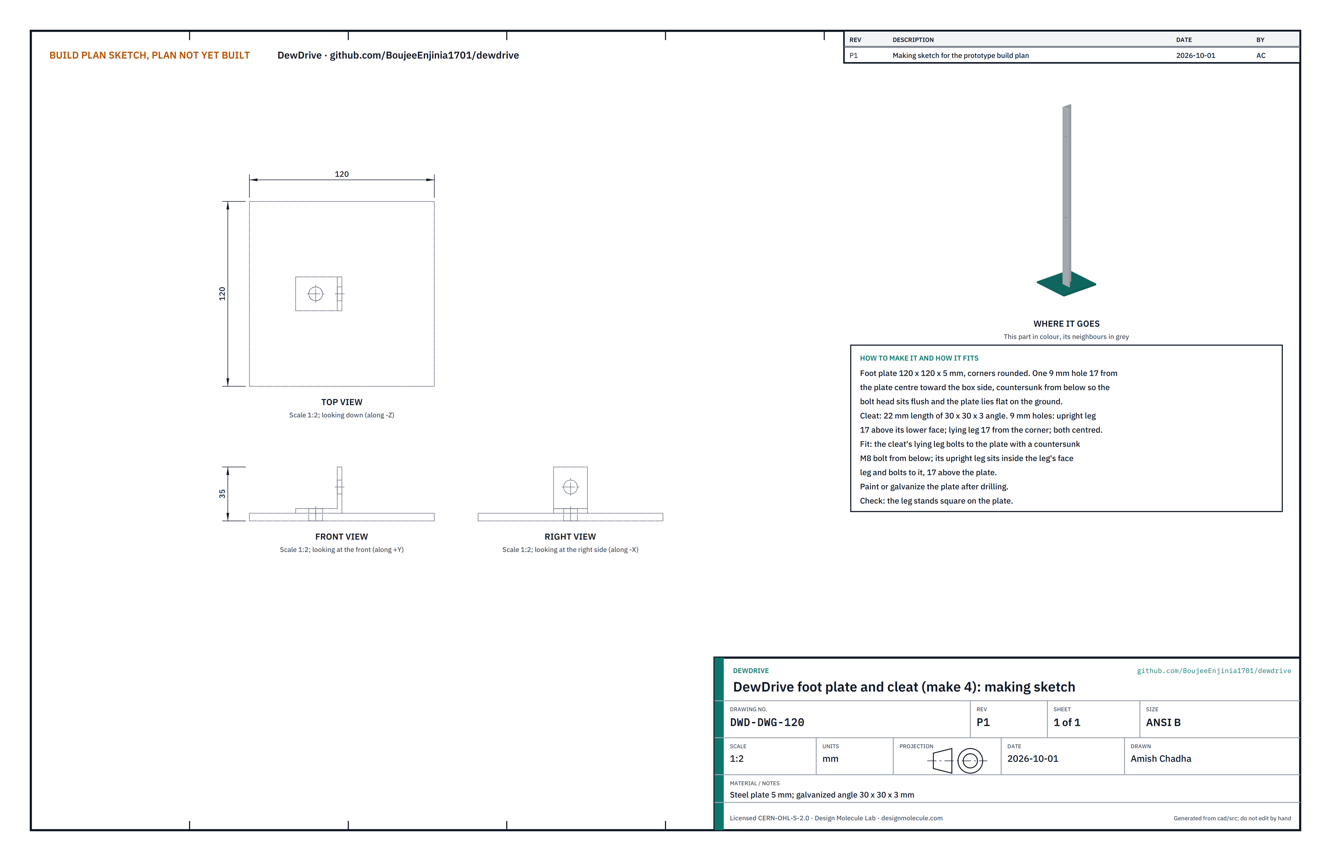
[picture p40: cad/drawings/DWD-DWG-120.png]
Figure 29. Making sketch of a foot plate and cleat


*Figure 29. Foot plate and cleat (DWD-DWG-120).*

**What it is and what it is made from.** A flat foot under each leg. Steel plate 5 mm, 120 x 120; cleat from galvanized angle 30 x 30 x 3, 22 long.

**How to make it.**

1. Cut the plates and round the corners. Drill one 9 mm hole 17 from the plate centre toward the box side and countersink it from below.
2. Cut the cleats. Drill 9 mm in each leg: the upright leg 17 above its lower face, the lying leg 17 from the corner, both centred.
3. Paint the plates with zinc-rich paint.

**How it fits the parts next to it.**

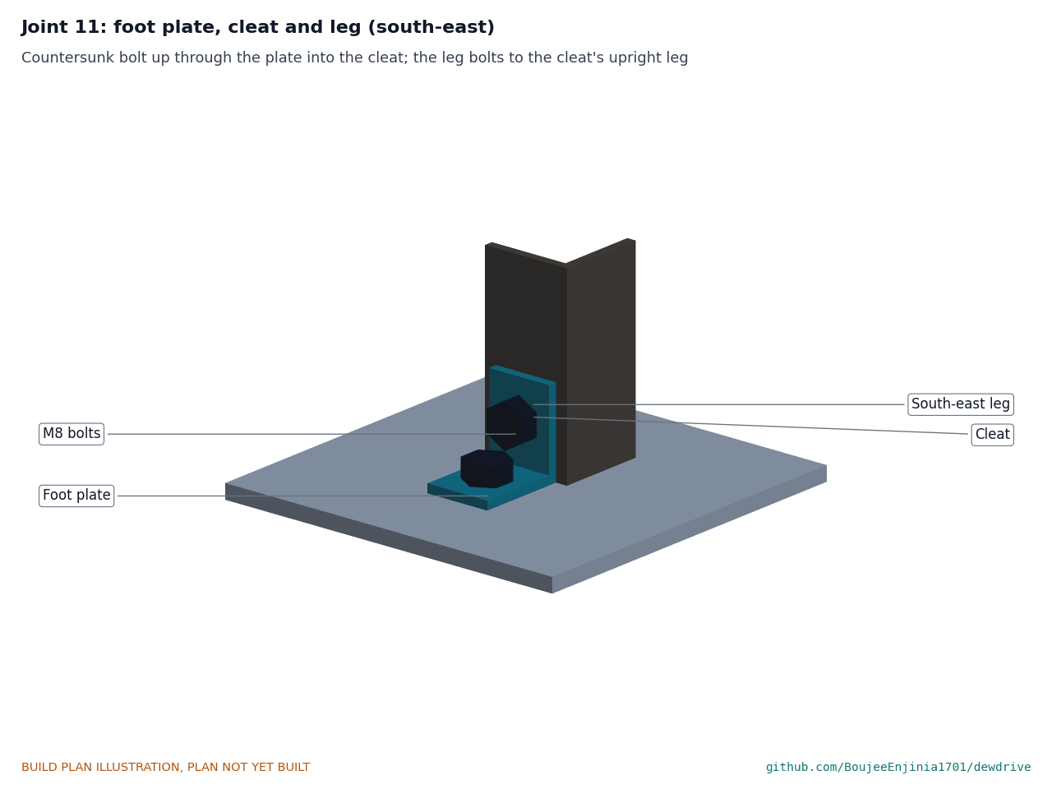
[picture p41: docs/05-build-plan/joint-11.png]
Figure 30. Joint 11: foot plate, cleat and leg


*Figure 30. A countersunk M8 bolt comes up through the plate into the cleat; the leg bolts to the cleat's upright leg.*

**Check before moving on.** The plate lies flat on a bench with the bolt in place; the leg stands square on it.

### 3.15 Side braces (make 2)

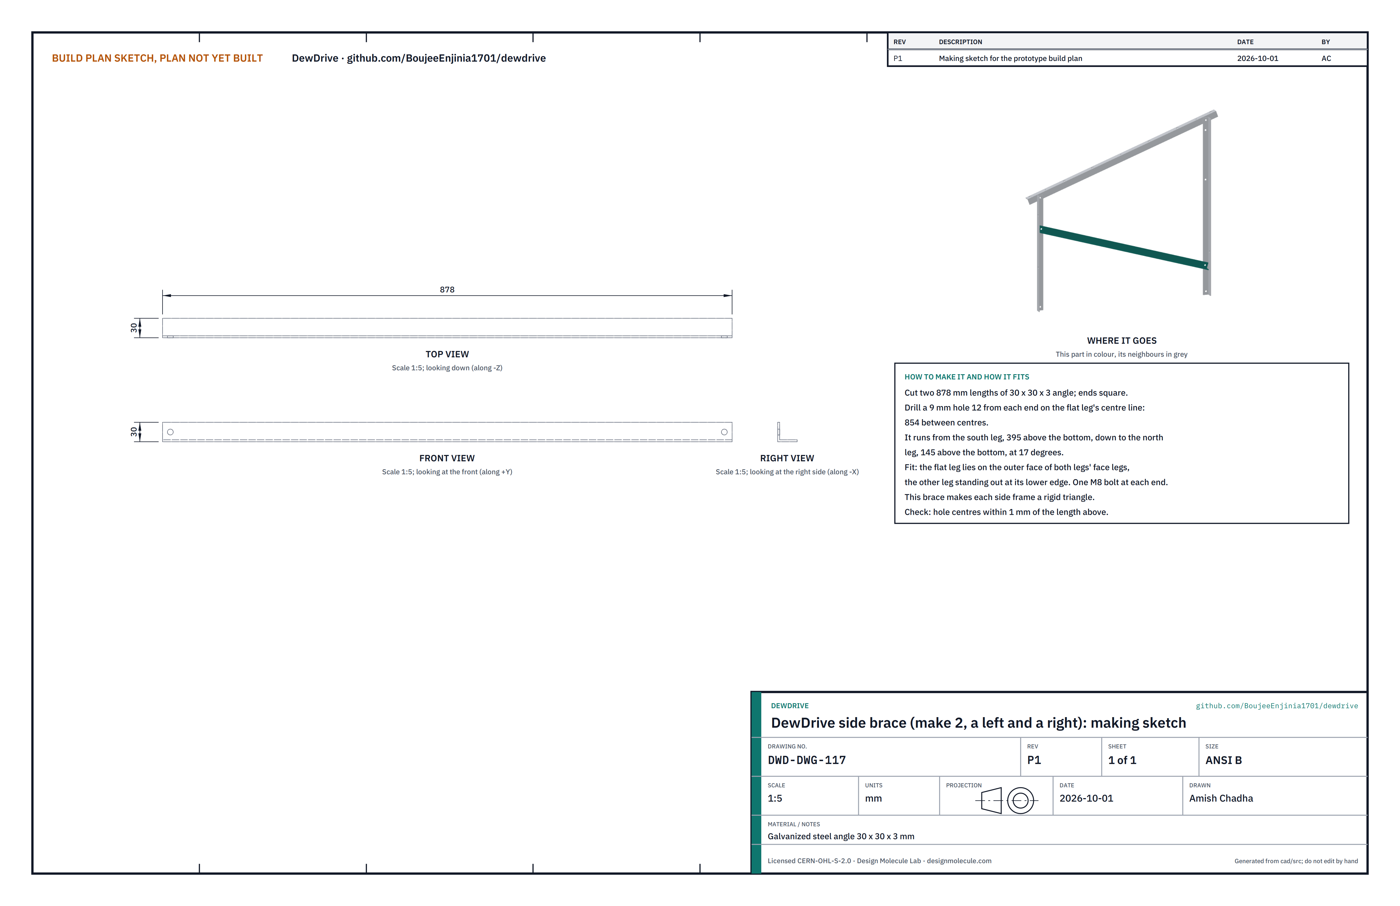
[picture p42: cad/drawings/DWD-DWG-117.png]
Figure 31. Making sketch of a side brace


*Figure 31. Side brace (DWD-DWG-117).*

**What it is and what it is made from.** The diagonal in each side frame, from high on the south leg to low on the north leg, which makes the side frame a rigid triangle. Galvanized steel angle 30 x 30 x 3, 878 long.

**How to make it.** Cut two lengths with square ends. Drill a 9 mm hole 12 from each end on the flat leg's centre line, 854 between centres. Drill as a pair; paint the ends.

**How it fits the parts next to it.**

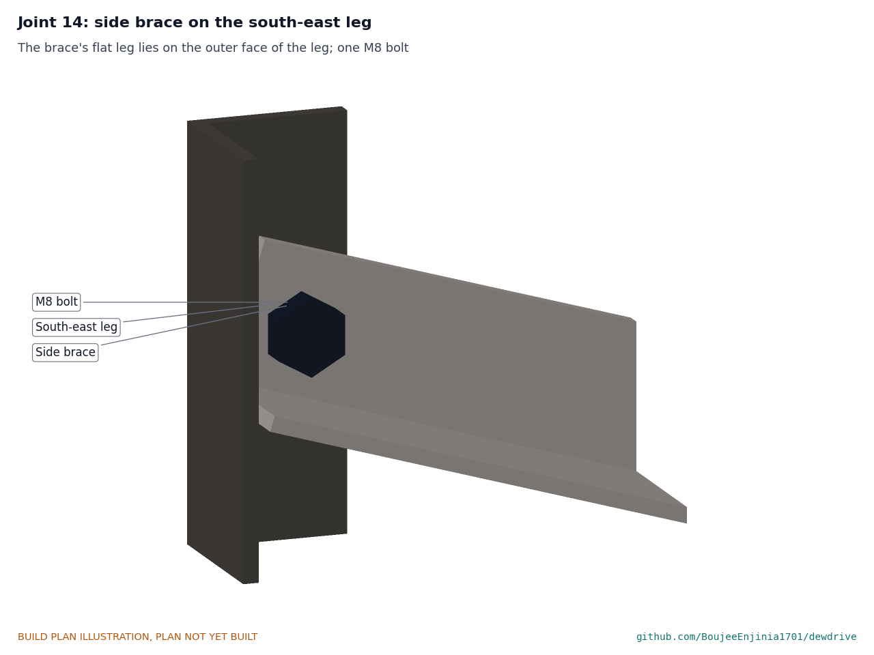
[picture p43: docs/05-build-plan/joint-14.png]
Figure 32. Joint 14: the side brace on the south-east leg


*Figure 32. The brace's flat leg lies on the outer face of the leg; one M8 bolt.*

The flat leg lies on the outer faces of both legs' face legs, its other leg standing out at the lower edge, and runs down at 17° from the south leg to the north leg.

**Check before moving on.** Hole centres within 1 of 854.

### 3.16 Cross members and south diagonal brace

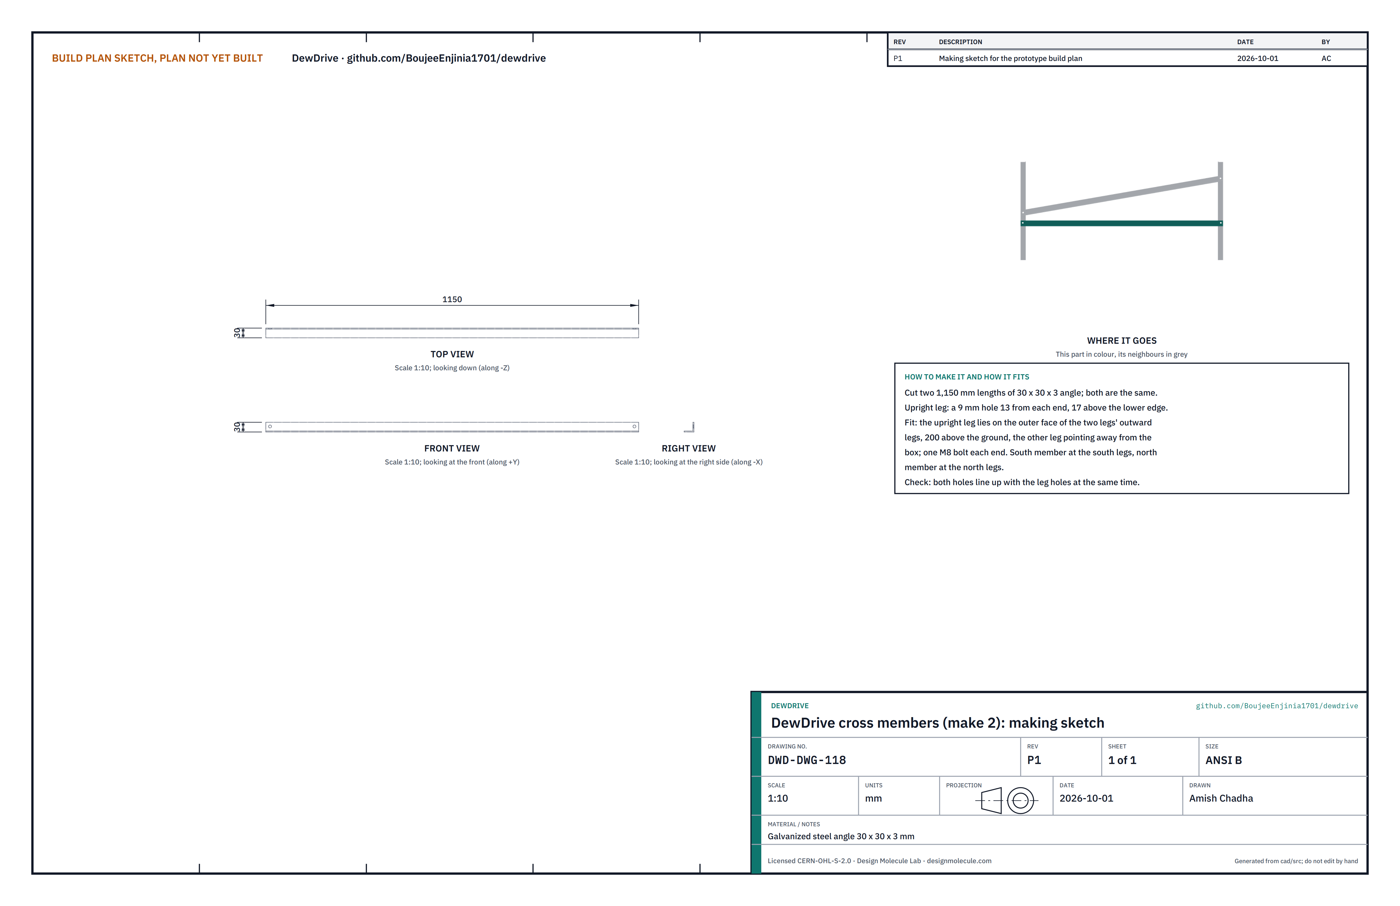
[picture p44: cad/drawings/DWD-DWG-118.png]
Figure 33. Making sketch of the cross members


*Figure 33. Cross members (DWD-DWG-118).*

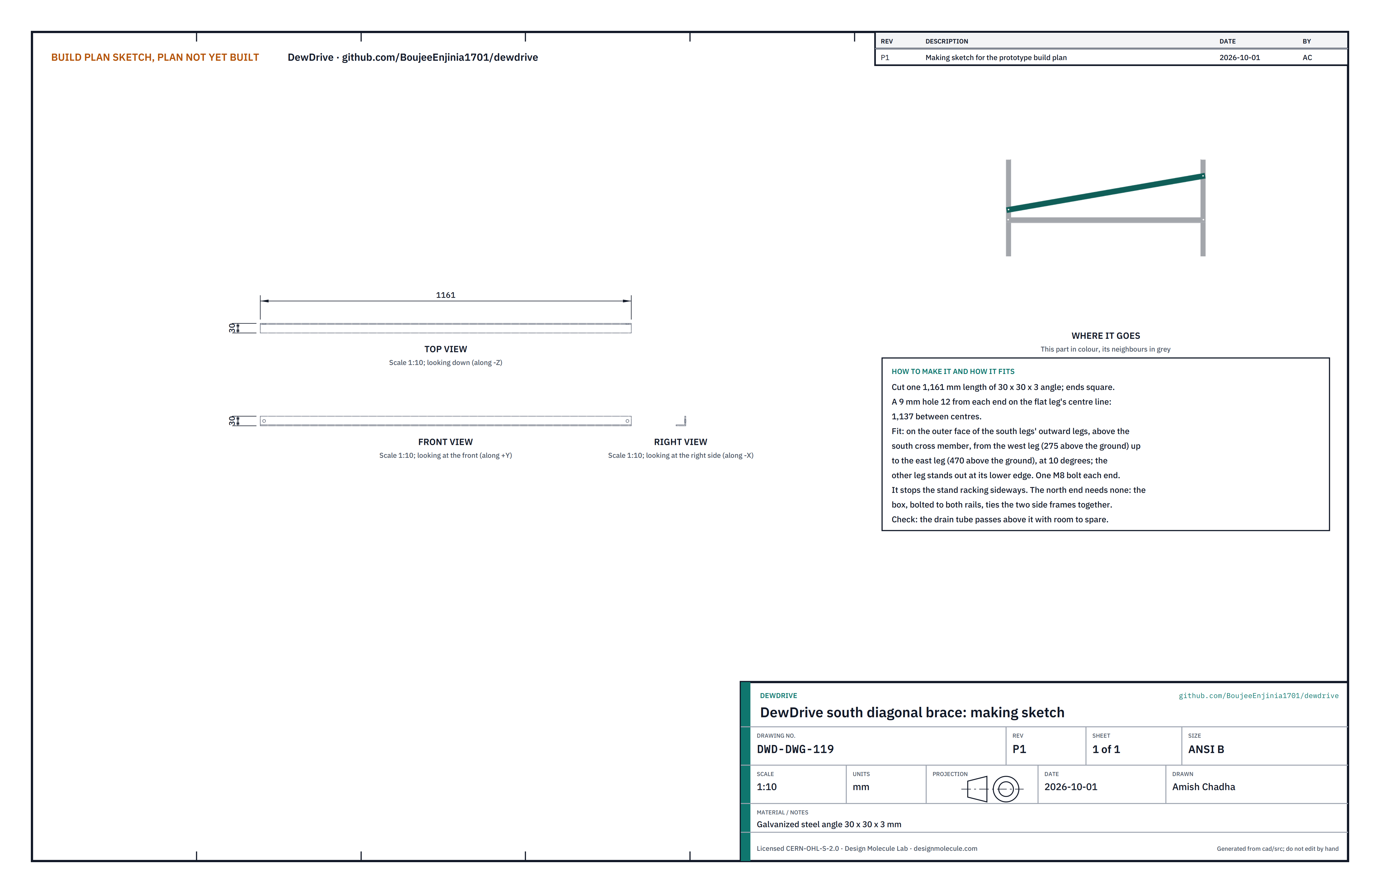
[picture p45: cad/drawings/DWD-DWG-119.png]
Figure 34. Making sketch of the south diagonal brace


*Figure 34. South diagonal brace (DWD-DWG-119).*

**What it is and what it is made from.** Two cross members that tie the legs together at each end, 200 above the ground, and one diagonal across the south end that stops the stand swaying sideways. Galvanized steel angle 30 x 30 x 3: cross members 1,150, diagonal 1,161.

**How to make it.**

1. Cross members: cut two lengths; drill a 9 mm hole 13 from each end, 17 above the lower edge of the upright leg.
2. Diagonal: cut one length; drill a 9 mm hole 12 from each end on the flat leg's centre line, 1,137 between centres.
3. Paint the ends and holes.

**How it fits the parts next to it.**

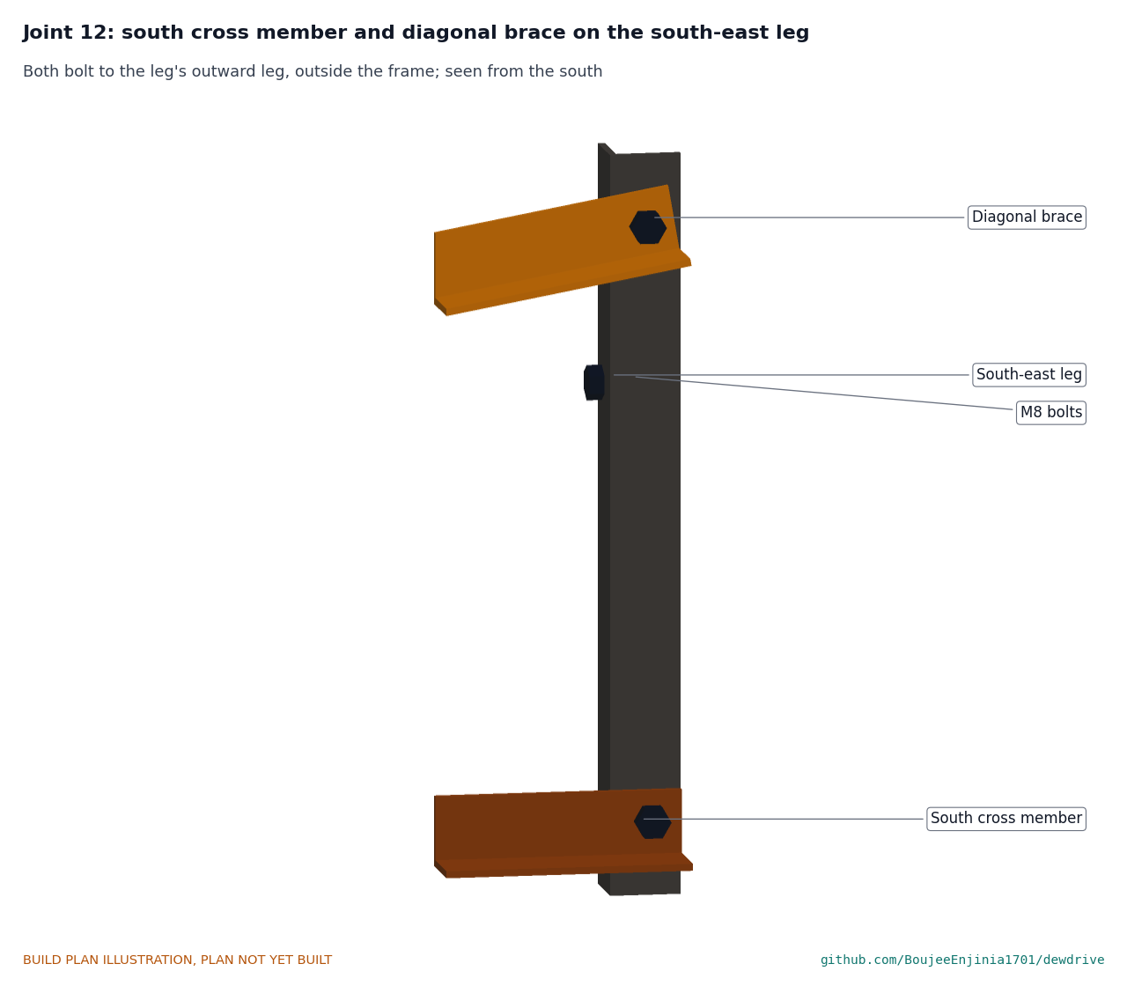
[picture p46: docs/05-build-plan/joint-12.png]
Figure 35. Joint 12: cross member and diagonal on the south-east leg


*Figure 35. Both bolt to the outer face of the leg's outward leg.*

Each cross member's upright leg lies on the outer faces of the two legs' outward legs, its other leg pointing away from the box, one M8 bolt each end. The diagonal lies in the same plane above the south cross member, from the west leg 275 above the ground to the east leg 470 above the ground. The north end needs no diagonal: the box, bolted to both rails, ties the side frames together.

**Check before moving on.** All holes line up with the leg holes at the same time with the rails level.

### 3.17 PV pole

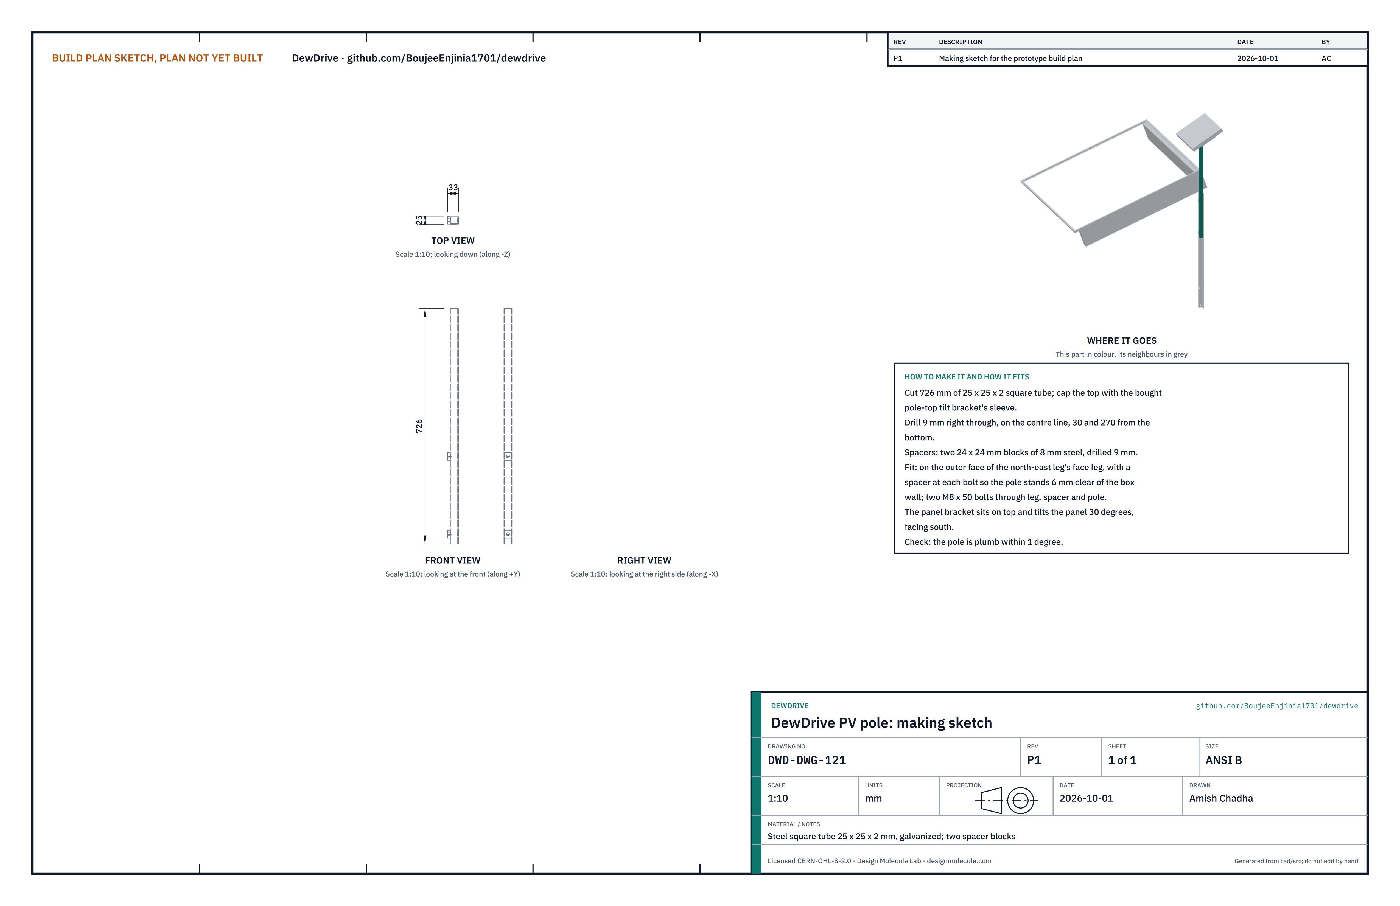
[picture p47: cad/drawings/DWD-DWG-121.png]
Figure 36. Making sketch of the PV pole


*Figure 36. PV pole (DWD-DWG-121).*

**What it is and what it is made from.** The pole that holds the 10 W panel above the north-east leg, north of the box where it cannot shade it. Steel square tube 25 x 25 x 2, galvanized, 726 long; two spacer blocks 24 x 24 x 8 steel.

**How to make it.**

1. Cut the tube; drill 9 mm right through, on the centre line, 30 and 270 from the bottom.
2. Cut and drill the two spacers 9 mm.

**How it fits the parts next to it.**

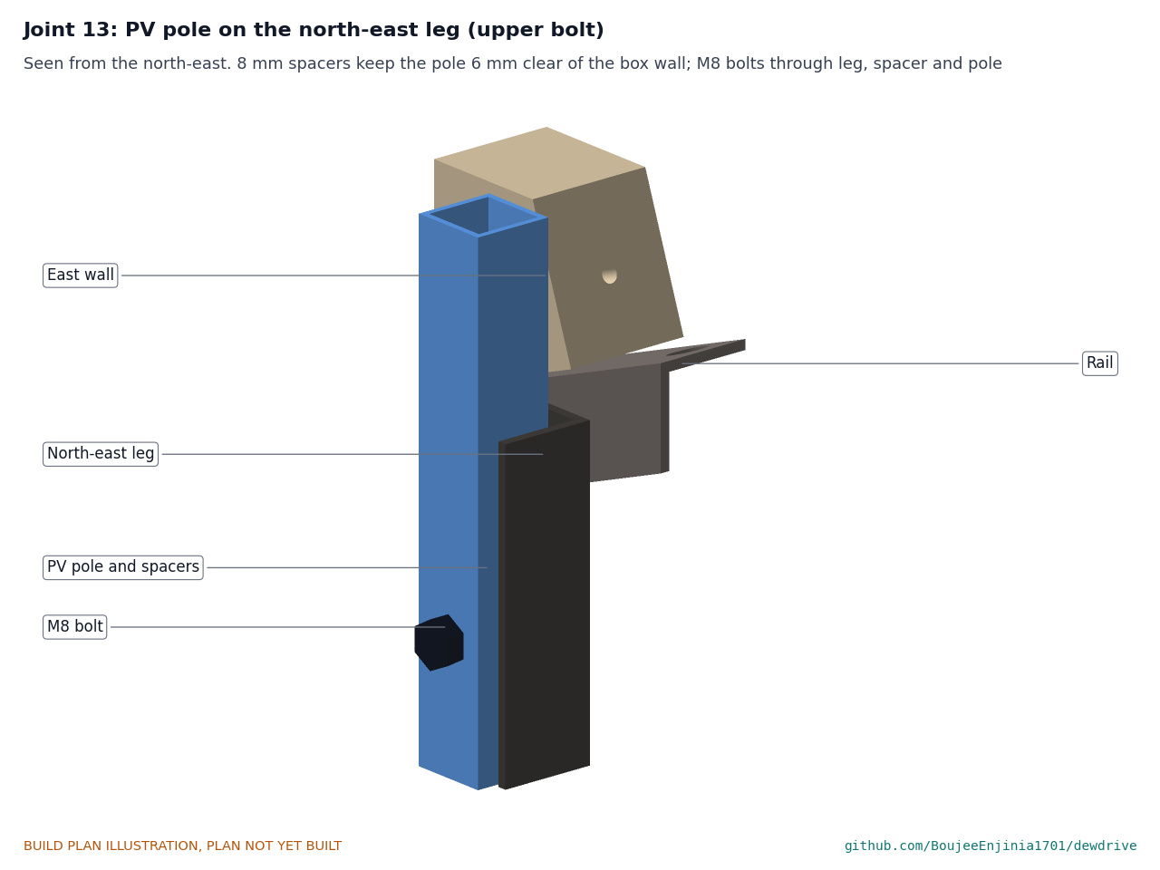
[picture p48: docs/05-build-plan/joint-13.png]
Figure 37. Joint 13: the pole on the north-east leg


*Figure 37. The spacers keep the pole 6 clear of the box wall.*

Two M8 x 50 bolts go through the leg's face leg, a spacer and the pole. The bought pole-top bracket sleeves over the top of the pole and tilts the panel 30° to the south.

**Check before moving on.** The pole is plumb within 1° and clears the box by at least 5.

### 3.18 Electronics backing plate and wiring

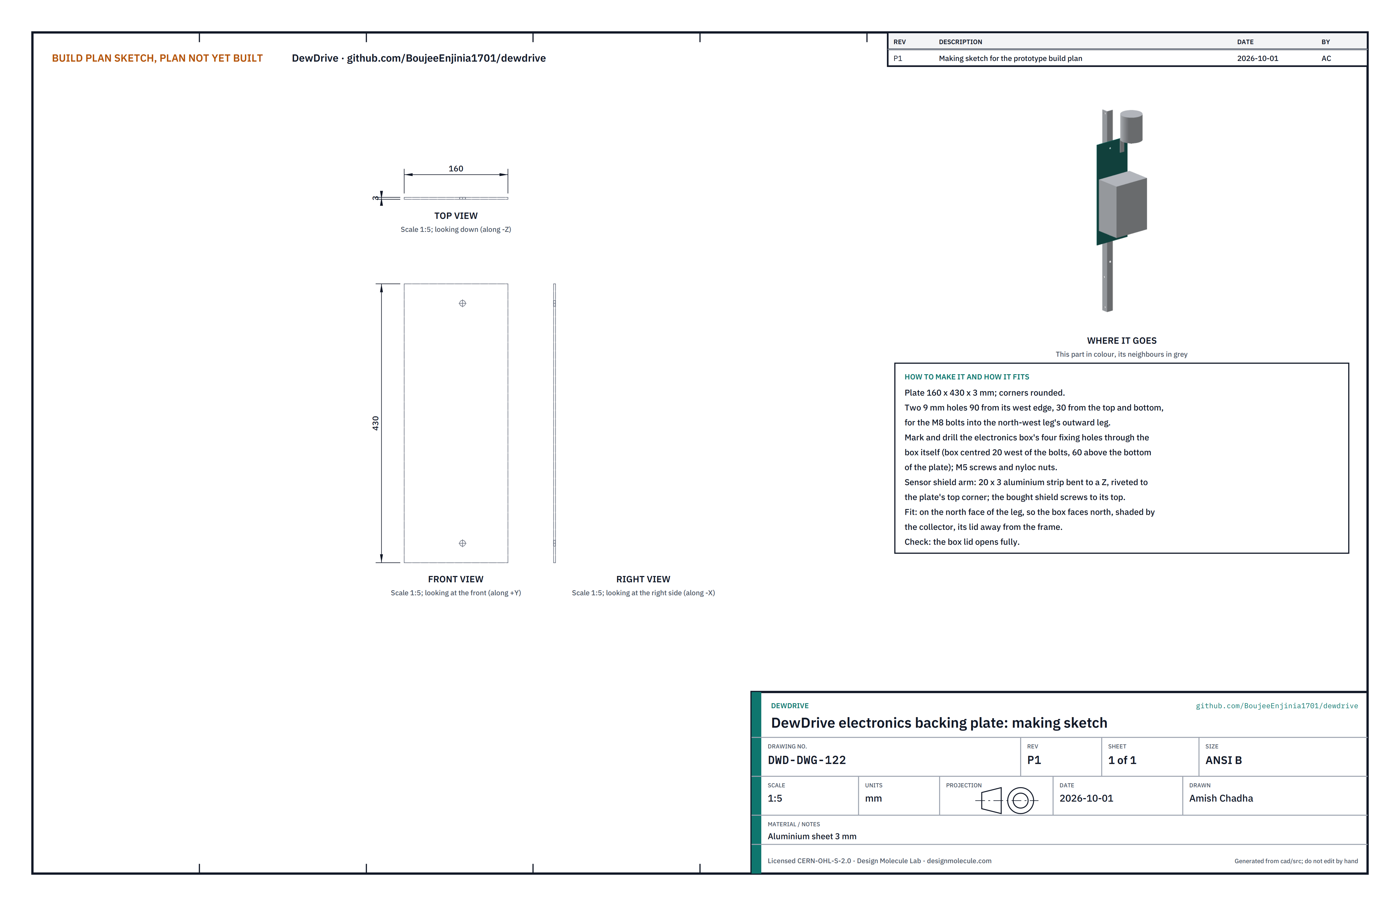
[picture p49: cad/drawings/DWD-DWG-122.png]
Figure 38. Making sketch of the backing plate


*Figure 38. Electronics backing plate (DWD-DWG-122).*

**What it is and what it is made from.** A plate on the north face of the north-west leg that carries the electronics box and, on a small arm, the air sensor's radiation shield. Aluminium sheet 3 mm, 160 x 430; arm from 20 x 3 aluminium strip.

**How to make it.**

1. Cut the plate and round the corners. Drill two 9 mm holes 90 from its west edge, 30 from the top and from the bottom.
2. Hold the electronics box on the plate, centred 20 west of the bolt line and 60 above the plate's bottom; drill through its fixing holes and fix it with M5 screws and nyloc nuts.
3. Bend the arm to a Z and rivet it to the plate's top corner; the bought shield screws to its top.

**How it fits the parts next to it.** Two M8 bolts through the plate and the leg's outward leg. The box faces north, in the collector's shade, with its lid away from the frame.

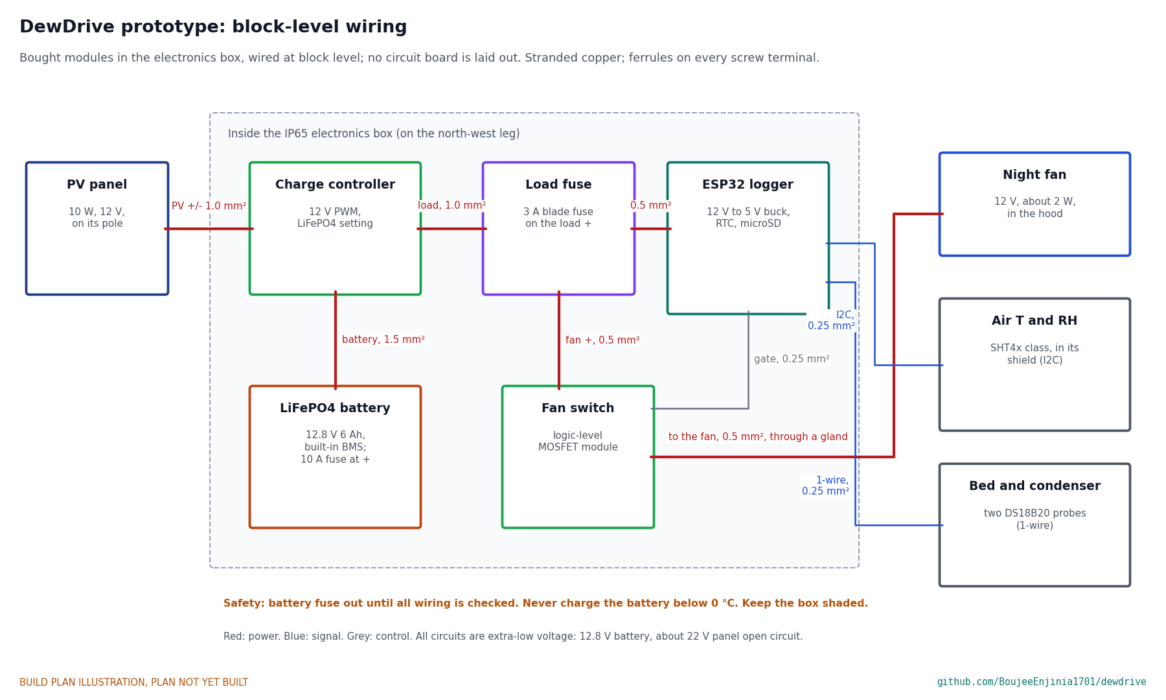
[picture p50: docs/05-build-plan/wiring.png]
Figure 39. Block-level wiring


*Figure 39. Block-level wiring with wire sizes. Bought modules; no circuit board is laid out.*

Wire it like this, with stranded copper and a ferrule on every screw terminal, the battery fuse out:

1. PV panel to the charge controller's panel input: 1.0 mm² (18 AWG), through a cable gland in the box bottom.
2. Charge controller to the battery, through the 10 A fuse at the battery's positive terminal: 1.5 mm² (16 AWG).
3. Controller load output, through a 3 A fuse, to the logger's 12 V to 5 V converter: 1.0 mm² then 0.5 mm² (20 AWG).
4. Load fuse to the fan switch module, and the switch to the fan: 0.5 mm², through a gland in the box and one in the hood.
5. Logger output pin to the switch module's input: 0.25 mm² (24 AWG).
6. Air temperature and humidity sensor to the logger (I2C) and the two probes (one taped under a tray, one on the condenser plate) to the logger (1-wire): 0.25 mm², twisted, cable-tied along the frame.

The logger needs firmware, which is TRL 4 work; for the first checks the fan is switched by hand from the bench (section 5).

**Check before moving on.** With the battery fuse out, every wire continues end to end and nothing reads short to the negative rail.

### 3.19 Bought components

Buy to specification, not brand. Line numbers are those of the bill of materials.

- **Glazing sheet (line 3).** 10 mm UV-stabilized twin-wall polycarbonate, 1,096 x 996, rated 130 °C or more (a 120 °C sheet only if the supplier's data and the inner-skin temperature measured at the first stagnation test both show it stays inside its rating), with breather and aluminium flute tape, EPDM seal, three 60 mm stainless butt hinges and two over-centre latches.
- **Tray floors (line 4).** 1 mm perforated aluminium, about 50 % open; stainless woven mesh, 1 mm aperture; EPDM gasket tape.
- **Silica gel and salt (line 5).** Mesoporous silica gel beads, 2 to 5 mm, about 1.0 cm³/g pore volume; food-grade anhydrous calcium chloride (E509).
- **Drain (line 7).** Food-grade bulkhead fitting with a 12 mm hose barb, for a 17 mm hole; 1 m of food-grade silicone tube, 12 mm bore.
- **Bottle (line 8).** 10 L food-grade HDPE jerrycan with a screw cap; fit a grommet in the cap for the tube.
- **Flap hardware (line 9).** 840 mm piano hinge; two small over-centre latches; EPDM foam seal.
- **Fan (line 10).** 12 V, 120 mm, about 2 W, IP55.
- **PV (line 11).** 10 W 12 V monocrystalline panel, about 340 x 250; pole-top tilt bracket for a 25 mm square pole.
- **Electronics (line 12).** IP65 box about 160 x 110 x 220; 12 V PWM solar charge controller with a LiFePO4 setting; 12.8 V 6 Ah LiFePO4 battery with built-in battery management and a 10 A inline fuse; ESP32 logger board with clock and microSD; 12 V to 5 V converter; logic-level MOSFET switch module; 3 A blade fuse; cable glands.
- **Sensors (line 13).** SHT4x-class air temperature and humidity sensor with a radiation shield; two waterproof DS18B20 probes.
- **Anchors (line 1).** Two auger ground anchors rated for 100 N or more of uplift in the site's soil, with two ratchet straps.
- **Fixings (line 14).** About 22 galvanized M8 bolts (25 to 50 long) with nuts and washers, and four countersunk M8 bolts for the feet; six M6 x 40 bolts and six M6 threaded inserts for wood; 24 M5 x 30 stainless button-head screws; 12 stainless 5 x 65 wood screws; 8 stainless 4 x 25 countersunk screws; 3.2 mm aluminium rivets (closed-end for the fins); food-grade silicone; polyurethane construction adhesive; high-temperature epoxy; EPDM gasket tape and lip seal; cable glands and ties; one outdoor vinyl label, 150 x 50, printed "Empty before lifting: remove trays, sorbent and deck".

## 4. Putting it together

In each picture the parts already fitted are grey and the parts being fitted are in colour, with an arrow showing the way they go in. Steps 1 to 12 are on the bench, with the box lying flat; steps 13 to 19 are at the site.

### Step 1: join the wall panels into a box

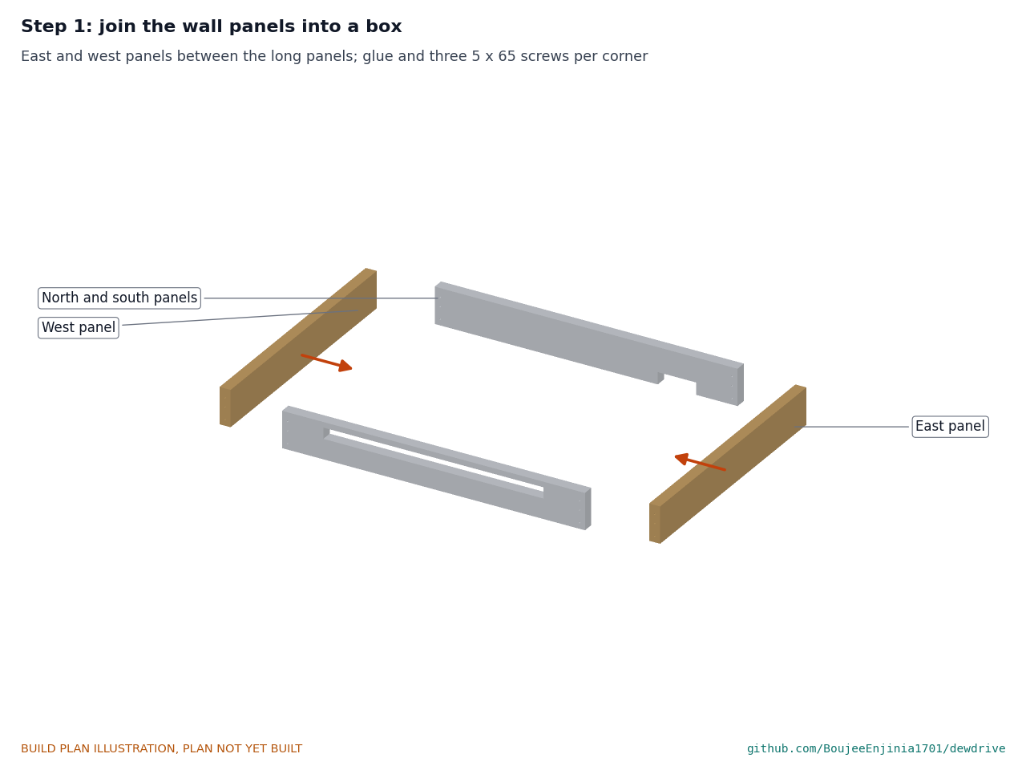
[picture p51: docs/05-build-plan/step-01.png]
Step 1


Glue each corner and drive three 5 x 65 screws through the long panel into the short panel's end post. Check the diagonals before the glue sets.

### Step 2: fins onto the condenser plate

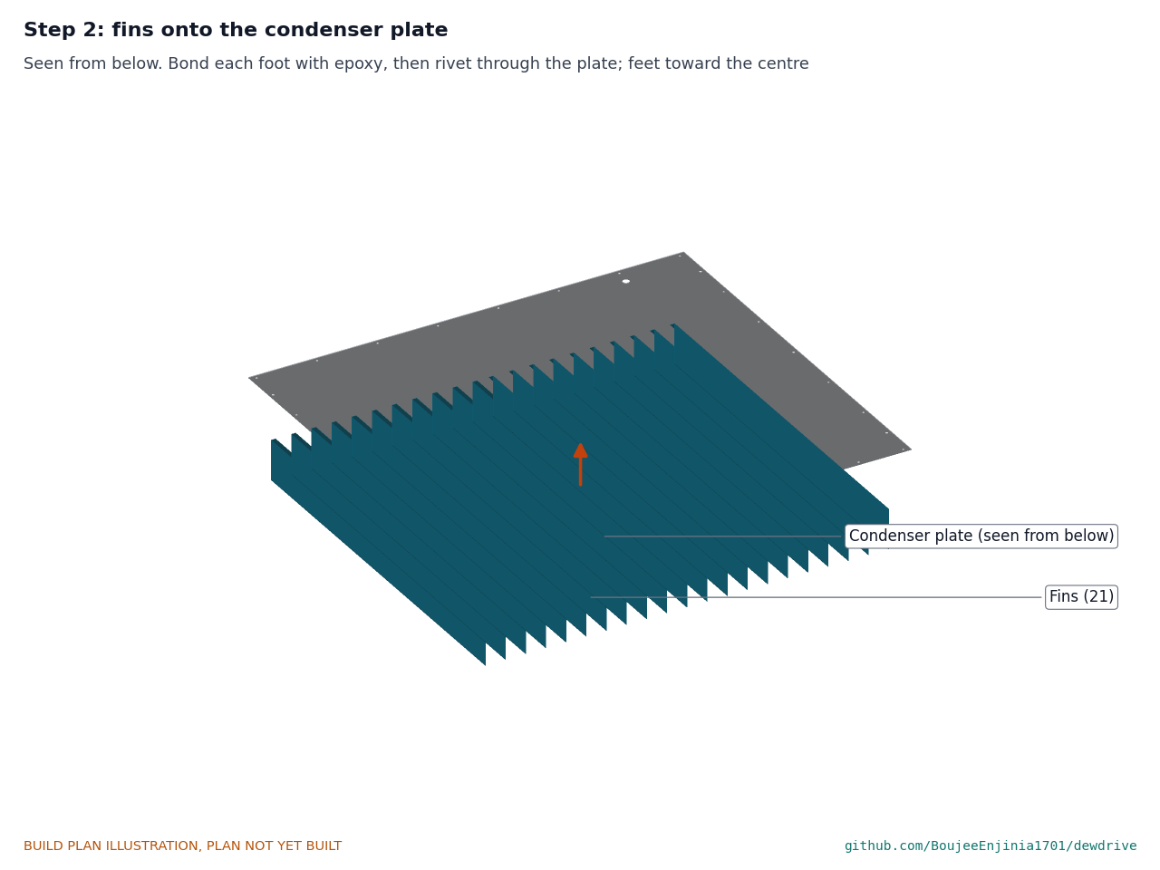
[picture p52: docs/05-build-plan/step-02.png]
Step 2


Plate top face down. Bond and rivet each fin as section 3.2 says. **Hold point:** the epoxy is fully cured before the plate is turned over.

### Step 3: box onto the plate

Step 3

EPDM gasket tape on the wall bottoms. Set the box on the plate, edges 10 inside the walls' outer faces all round, and drive the 24 M5 screws up through the plate into the bottom battens. Then coat the plate's top face (section 3.2, item 5).

### Step 4: gutter and drain fitting

Step 4

Bed the gutter in silicone along the south wall; fit the drain fitting down through the gutter and the plate, washer on top, nut below.

### Step 5: wall ledges

Step 5

Screw a ledge to the inside of the east and west walls, its top level with the top of the bottom batten.

### Step 6: baffle onto the deck frame

Step 6

On the bench: rivet the baffle to the frame, then stick the gasket tape round the openings and the lip seal round the edge.

### Step 7: drip screens under the deck

Step 7

Turn the deck upside down. Rivet each screen's sump tab and end plate tab to the faces of the deck bars, sumps toward the south (low) edge.

### Step 8: deck into the box

Step 8

Lower the deck, screens down, level onto the two ledges. The lip seal should touch the walls all round.

### Step 9: trays onto the deck

Step 9

Fill each tray with 1.0 kg of dry sorbent (section 3.8) and set it on the gasket round its opening. **Hold point:** wear gloves; trays that have been in sun are hot.

### Step 10: the lid

Step 10

Stick the EPDM seal on the wall tops. Set the lid on, screw the hinge leaves into the north wall's top batten and the latch bodies to the south wall.

### Step 11: inlet flap

Step 11

Screw the piano hinge's free leaf into the south wall's top batten and the latch bodies into the sill batten.

### Step 12: fan, hood and outlet flap

Step 12

With the fan already in the hood, screw the hood over the outlet slot through its flanges, bedded in silicone. Pass the fan lead through the gland in the hood's bottom.

### Step 13: the two side frames

Step 13

At the site, on level ground. Bolt the cleats to the foot plates and the legs to the cleats. On the ground, bolt each side frame together: south leg, north leg, rail and side brace. Stand them up with the rails' outer faces 1,090 apart.

### Step 14: cross members and diagonal brace

Step 14

Bolt both cross members, then the diagonal. Check that the two rails are level with each other and square to the cross members, then tighten every bolt.

### Step 15: ground anchors

Step 15

Screw each anchor in 190 outside a south leg and strap it to the leg with a ratchet strap. **Hold point:** safety stop S4.

### Step 16: box onto the stand

Step 16

Take the trays, the sorbent and the deck out of the box first. Stick the label that reads "Empty before lifting" on the outside of the east wall, above the middle bolt position, where both lifters can read it (the small yellow patch in the picture). Then two people lower the box onto the rails so the rail holes line up with the inserts, and drive the six M6 bolts up into the inserts. Then put the deck, the sorbent and the trays back.

### Step 17: PV pole and panel

Step 17

Bolt the pole to the north-east leg on its spacers. Fit the bracket and the panel, tilted 30° to the south.

### Step 18: electronics and sensor shield

Step 18

Bolt the backing plate to the north-west leg. Fit the box, the sensor shield and the probes; run the cables along the frame with ties and wire them as Figure 39. **Hold point:** safety stop S5.

### Step 19: bottle and drain tube

Step 19

Push the tube onto the fitting's barb and run it down over the diagonal brace to the bottle, through the grommet in its cap.

## 5. First checks

These are the checks a TRL 4 test report would record; this plan only lists them. Requirement numbers are those of DWD-REQ-001.

*Table 2. First checks.*

| Check | Requirement | How | Pass when |
| --- | --- | --- | --- |
| Box sealed by day | R1, R2 | Lid and flaps shut; smoke pencil round the lid seal, flaps and hood with a little fan suction | No smoke drawn in anywhere except at the fan |
| Air passes through the beds | R1, R2 | Flaps open, fan on from the bench at 12 V; smoke at the inlet | Smoke is drawn in at the inlet and leaves at the fan; none rises past the deck edge |
| Fan supply | R4 | Measure the fan current at 12.8 V | About 0.15 A (2 W) or less |
| Charging | R4 | Panel connected in sun, battery fuse in | Controller shows charging; battery voltage rises |
| Condensate path | R6, R7 | Pour 0.5 L of clean water on the plate at the high edge | All of it reaches the bottle; none stands on the plate or touches wood |
| Sumps clear of the water path | R7 | Pour 50 mL into one sump with the deck in place | No water reaches the plate or gutter |
| Bed and touch temperatures | R3, R13 | Probes logged on a clear day, flaps shut | Bed 75 °C or more by midday; glazing outer skin 60 °C or less |
| Box mass | R9 | Weigh the box with and without the trays and deck | Within 2 kg of 35.2 and 23.4 kg |
| Anchors and stand | R10 | Pull up on each anchor strap; push the box corners by hand | No movement of anchors or joints |
| Daily operation | R8 | Time opening both flaps at dusk and closing them at dawn | 5 minutes or less in all |
| Logging | R12 | Run the logger for 24 hours | Every channel recorded every 5 minutes |

## 6. Safety stops

Stop at each point. Carry on only when everything listed is true.

- **S1. Before mixing the sorbent.** Gloves and eye protection on; a plastic or stainless tub; water to rinse eyes and skin within reach; the salt added to water, never water to dry salt in a closed container.
- **S2. Before drying the sorbent.** An oven or collector that cannot pass 160 °C; nothing combustible touching the beads; ventilation.
- **S3. Before the lid is first closed in sun.** The glazing sheet's rating is 130 °C or more (confirmed from the supplier), or a 120 °C sheet is backed by the supplier's data and its inner skin is logged at the first stagnation test; "Hot surface" labels on the glazing; the trays sit on the deck with no brine visible.
- **S4. Before the box goes on the stand.** Every stand bolt tight; both anchors in and strapped (or about 40 kg of ballast on the cross members); two people for the lift; the trays and deck out of the box, and the "Empty before lifting" label on the box.
- **S5. Before the battery fuse goes in.** Wiring checked against Figure 39 with a meter, not by wire colour; the controller set to LiFePO4; the battery undamaged, above 0 °C and in the shade of the collector.
- **S6. Before anyone drinks the water.** A laboratory test of the collected water (chloride, metals, bacteria); until then, boil or disinfect it and treat it as a supplement only.
- **S7. Before emptying the sumps.** The box cool; gloves and eye protection; the deck lifted out and tipped over a bucket, away from the water bottle.

## 7. Tools, skills and workspace

**Tools.** Circular saw or panel saw and a fine handsaw; drill and bench drill; drills 3 to 12 mm and a 17 mm step drill; countersink; jigsaw with wood and metal blades; aviation snips; a sheet-metal folder or hardwood battens and clamps for bends up to 1,100 long; hand rivet tool; files and deburring tool; hacksaw or angle grinder with a cutting disc for steel angle; spanners and sockets 10 and 13 mm; screwdrivers; clamps; steel rule, tape, square and spirit level; angle finder; caulking gun; multimeter; crimper and wire strippers; kitchen scale to 5 kg and bathroom scale; oven or the collector for drying the sorbent.

**Skills.** No certified trade is needed. Basic woodworking (cutting, gluing and screwing panels square), thin sheet-metal work (marking out, snipping, folding, drilling and riveting), drilling and bolting steel angle, and low-voltage DC wiring. All circuits are extra-low voltage: 12.8 V at the battery and about 22 V open circuit at the panel.

**Workspace.** A flat bench about 2.4 x 1.2 m for the box and deck; a metalwork area kept apart from the electronics; a ventilated outdoor place for mixing and drying the sorbent; level ground at the site with room to walk round the unit.

**Personal protective equipment.** Safety glasses for cutting, drilling and riveting; chemical splash goggles and nitrile gloves for the sorbent and sumps; cut-resistant gloves for sheet and angle; hearing protection for the saws and grinder; heat-resistant gloves for anything that has been in sun.

## 8. Where the numbers come from

- Model and constructability checks: `cad/src/model.py` (`python cad/src/model.py --check`, 91 checks); STEP and STL exports in `cad/step/` and `cad/stl/`.
- Pictures: `cad/src/build_plan_media.py`, using `.kit/build_views.py`; written to `docs/05-build-plan/` and `cad/drawings/DWD-DWG-101` to `DWD-DWG-122`.
- General arrangement: `cad/drawings/DWD-DWG-001.pdf`, Rev P5.
- Calculations: `docs/04-calcs/01-sizing.md` (DWD-CAL-001 v0.5) and `docs/04-calcs/sizing.py`; mass [G1], [G2], fan duty [F3], wind [H1] to [H4], sorbent and bed [A5], salt containment [E1] to [E6].
- Bill of materials: `bom/bom.csv`.
- Decisions: `docs/decisions/0003-design-for-construction.md` (DWD-DDR-003), with DWD-DDR-001 and DWD-DDR-002.
- Requirements: `docs/03-requirements.md` (DWD-REQ-001 v0.7).

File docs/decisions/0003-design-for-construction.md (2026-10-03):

---
doc_id: DWD-DDR-003
title: DewDrive design for construction
project: DewDrive
doc_type: Design decision record
version: "0.4"
status: Draft
date: '2026-10-02'
author: Amish Chadha
license: CERN-OHL-S-2.0
revisions:
- version: "0.1"
  date: '2026-10-01'
  author: Amish Chadha
  change: Changes that make the concept physically buildable, with the reason for each; made under Amish's 2026-09-30 instruction to make the design physically buildable; open for his review
- version: "0.2"
  date: '2026-10-01'
  author: Amish Chadha
  change: Budget treated as a value-engineering target
- version: "0.3"
  date: '2026-10-02'
  author: Amish Chadha
  change: Accepted by Amish on 2026-10-02, including the recommendation for A2
- version: "0.4"
  date: '2026-10-02'
  author: Amish Chadha
  change: Consequences updated after the follow-ups (cost USD 639, status from DWD-CAL-001 v0.7, appearance model brought into line)
---

# 0003: Design for construction

- **Date:** 2026-10-01
- **Status:** accepted. Amish, 2026-10-02: "i approve your recommendations for all 555 open decisions." This covers every change in Tables 1 and 2, as made, and the recommendation for A2 in Table 3, which is now decided as recommended and recorded in the design decisions register (DWD-DEC-001).

## Context

On 2026-09-30 Amish asked for the build plan to show how each component is made and how it fits the next, with pictures, and wrote: "If you are realising that the design cannot be built as per concept - fix the design assumptions to match and be physically feasible as you draw the illustrations." The model behind DWD-DDR-002 was a massing model: it showed what DewDrive does, but many of its parts could not be made or fixed as drawn. Checking it with build123d found, among others, that the condenser plate overlapped the walls by 240 cm³, the stand ran through the condenser (12 cm³) and the walls (143 cm³), the PV pole passed through the box (56 cm³), and the drip screens floated 7 mm below the trays with nothing holding them.

Every change below keeps what DewDrive does: the same glazed, insulated 1.1 x 1.0 m box at 20°, the same trays, bed, gaps, drip screens, condenser area and fins, the same night air path down through the beds, the same fan, flaps, panel, battery and logger. The water, heat, salt and electrical results of DWD-CAL-001 are unchanged. The changes are all in `cad/src/model.py`, which now builds every made or bought piece as its own component with its material, and runs 91 constructability checks (`python cad/src/model.py --check`): parts that must touch do touch, and parts that must not touch are apart by at least a stated clearance. All 91 pass.

## Decision

*Table 1. Changes made to the model, the BOM and the calculations.*

| # | Problem in the concept | Change made | Why this way |
| --- | --- | --- | --- |
| P1 | The 1,080 x 980 mm condenser plate sat inside the walls at the height of their bottom edge, overlapping them by 240 cm³; nothing sealed or fixed it. | The plate now closes the bottom of the box: the walls stand on its top face, on EPDM gasket tape, and 24 M5 screws go up through it into the wall bottom battens. The walls start 5 mm higher (45 mm in the box frame, was 40) and are 133 mm tall (was 140), so the plate's wetted face, the trays, the glazing and every gap keep their heights. | The plate is the floor of a sealed box; screwing it to the walls from below keeps the vapour in and needs no extra frame. Keeping the heights keeps the heat and vapour calculations valid. |
| P2 | The walls were one solid block with no edges to screw into, no way to join the corners and no frame round the openings. | Four panels: 6 mm plywood skins glued to a 28 mm core of softwood battens (28 x 44 mm at the bottom, 28 x 20 mm at the top, 28 x 28 mm end posts) with 25 mm PIR foam in the bays. East and west panels fit between the long panels; three 5 x 65 mm screws per corner. The inlet opening and outlet slot are framed with battens. Six M6 threaded inserts in the east and west bottom battens take the bolts from the stand. | A sandwich panel needs solid timber wherever a screw goes. The battens carry the plate screws, the ledge screws, the lid hinges and latches and the stand bolts. |
| P3 | The sealing baffle was a 1 mm sheet spanning 1 m, carried on two rails along the east and west walls only, and the rails were fixed to nothing. It could not carry four filled trays. | A tray deck: a frame of 20 x 5 mm aluminium flat bar on edge (outside 1,016 x 916 mm, with a centre cross), corners joined by riveted angle brackets, with the 1 mm baffle riveted on top. It rests on two 15 x 15 x 2 mm angle ledges screwed to the east and west walls. An EPDM lip seal closes the 2 mm gap to the walls; EPDM tape round each opening seals the tray lips. New BOM line 16. | By hand calculation the frame sags about 3 mm at its centre under four full trays, which the gasket tape takes up; a heavier bar is an option if a trial shows the tray lips lifting. The deck lifts out, with the drip screens under it, so the sumps can be emptied. The seal keeps the night air going down through the beds, as DWD-DDR-002 (D9) requires. |
| P4 | The drip screens floated 7 mm below the trays with no support, and each brine sump overlapped the ends of the lower channels. | Each screen is a riveted frame: two 1 mm side plates, four 15 x 2 mm cross straps carrying the channels, a sump at the low end and an end plate at the high end. The sump and the end plate each have a tab riveted to a bar of the deck. The sump now sits below the channel ends (it moved 2 mm north) and both channel layers sit 2 mm lower. | Hung from the deck, the screens never touch the condenser or the water path, and come out with the deck. The sump volume (0.58 L), the channel layers and the screen depth used in DWD-CAL-001 are unchanged. |
| P5 | The fins were 1 mm strips standing on their edges against the plate; an edge cannot be riveted or bonded. | Each fin has a 10 mm folded foot, bonded with high-temperature epoxy and fixed with closed-end aluminium rivets at 150 mm pitch. Feet point toward the centre line. | A folded foot gives a face to bond and rivet; closed-end rivets keep the box sealed. The fin depth, length, number and pitch are unchanged. |
| P6 | The gutter was a closed channel standing on the plate, so water running down the plate could not get into it; the drain went out through the south wall 8 mm above the plate. | The gutter is a folded L along the south wall: a 30 mm flange on the plate (water runs over its 1 mm edge) and a 16 mm upstand protecting the plywood. The drain goes down through the gutter and the plate with a food-grade bulkhead fitting, 370 mm east of centre, between two fins. | Water collects in the lowest corner and leaves by gravity; nothing wet touches the plywood. |
| P7 | The concept had a separate 560 x 70 mm outlet flap below the trays beside the fan. With both open at night, the fan would draw outside air in through that flap and out again, past the beds, so almost no air would pass through the sorbent. Also, a 120 mm fan cannot fit in the 65 mm space under the trays. | One outlet: a 140 x 44 mm slot through the north wall below the deck, covered outside by a 160 x 64 x 130 mm hood that holds the fan in its front. The outlet flap (140 x 125 mm) closes the fan opening by day. The fan duty is now about 3.3 Pa (F3). | All the air the fan moves must now enter at the inlet above the deck and pass down through the beds, which is what DWD-CAL-001 assumes. The hood gives the fan room outside the box. |
| P8 | The inlet opening ran from 138 to 178 mm in the box frame, leaving 2 mm of wall above it: no room for a top batten, the lid seal or the flap hinge. | Same 800 x 40 mm opening, now from 118 to 158 mm: still above the deck (110 mm), its head is the wall's top batten. | Keeps the inlet area and the night air path; the wall keeps a solid top edge for the lid seal and the flap hinge. |
| P9 | The lid was a polycarbonate slab resting on the walls, with no frame, hinge, latch or seal. | The sheet sits in a mitred aluminium U-channel frame on an EPDM seal on the wall tops, with three hinges on the north wall and two over-centre latches on the south wall. Its underside stays at 180 mm. | A twin-wall sheet needs its edges held and its flutes closed; the latches press the seal by day. |
| P10 | The stand's rails ran through the condenser and the walls, the legs had no joint to the rails, nothing held the box to the stand, and nothing stopped the stand swaying sideways. | Rails of 30 x 30 x 3 mm angle lie under the plate's east and west edges and bolt up into the wall inserts (six M6 bolts). Each leg's face bolts to its rail's hanging leg (one M8 bolt) and is cut square 3 mm below the rail top. A side brace on each side, cross members at both ends, and a diagonal brace across the south end. Foot plates with bolted cleats. All joints bolted, M8. | Every joint is face to face and bolted. The side frames are rigid triangles; the south diagonal and the box, bolted to both rails, stop the stand racking. The box still lifts off the stand (R9). |
| P11 | The PV pole passed through the north-east corner of the box (56 cm³). | A 25 x 25 x 2 mm square steel tube bolted to the north-east leg with two 8 mm spacers, 6 mm clear of the wall, with a pole-top tilt bracket. | Two bolts and no welding; the panel stays north of the box where it cannot shade it. |
| P12 | The electronics box and sensor shield hung in the air beside the north-west leg. | A 160 x 430 x 3 mm aluminium backing plate bolted to the north face of that leg carries the box and, on a small arm, the sensor shield. | The box sits in the collector's shade with its lid facing out. |
| P13 | The trays were drawn as 8 mm thick blocks with a 1 mm floor; a woven mesh across 474 x 414 mm would sag under 1 kg of sorbent. | Pans folded from 1 mm sheet with an 8 mm inward bottom lip, and a floor of 1 mm perforated aluminium (about 50 % open) under a fine stainless woven mesh. | The tray outside size, the bed area and the bed depth are unchanged. |

*Table 2. Knock-on changes.*

| Item | Change | Reason |
| --- | --- | --- |
| Mass | Box with everything inside 35.2 kg (was 33.4 kg), 23.4 kg with the trays, sorbent, deck and screens lifted out; stand 16.6 kg; total 60.2 kg (was 53.9 kg) [G1, G2]. | Battens, deck, screen frames, lid frame, fin feet and stand bracing; and v0.4 of the note weighs each component with its own material instead of averaged massing densities. |
| Cost | BOM lines 1 to 4, 6, 7, 10 to 12, 14 and 15 repriced and line 16 added: $620 (was $515) against the unchanged $520 value-engineering target (`budget_usd`) [J1]: $100 over. | Parts added for construction; cost drivers and savings are in the Value engineering section of the design decisions register. |
| Wind | Ballast for a factor of 1.5 now 40 kg (was 46 kg); each anchor 98 N (was 114 N) [H2, H4]. | Heavier unit. |
| Fan | About 3.3 Pa (was 0.4 Pa) [F3]; well within a 120 mm fan at low speed. | The outlet slot of P7. |
| Drawings | DWD-DWG-001 Rev P4; making sketches DWD-DWG-101 to 122. | Follow the model. |
| Documents | DWD-CAL-001 v0.5, DWD-REQ-001 v0.7, DWD-PRC-001 v0.7; build plan DWD-BLD-001 and design decisions register DWD-DEC-001 added. | Follow the model. |
| Unchanged | Water (0.57 and 0.45 L per day), bed and stagnation temperatures, condenser rise, salt containment, electrical energy. | No change to the box's heights, areas, bed, screens or condenser. |

*Table 3. Item that changes a requirement: proposed, then accepted by Amish as recommended on 2026-10-02.*

| # | Question | Options | Recommendation |
| --- | --- | --- | --- |
| A2 | Portability (R9). The full box is 35.2 kg against the 35 kg two-person limit; with the trays, sorbent, deck and screens lifted out (as the build plan does before any lift) it is 23.4 kg. | (a) restate R9 as "box 35 kg or less when lifted with the trays and deck taken out"; (b) take about 0.5 kg out (1.5 mm screen straps and deck brackets, a lighter lid channel) and keep R9 as written. | (a): lifting the box with brine sumps and loose sorbent inside should be avoided anyway; the 0.2 kg excess is inside the accuracy of the estimate. **Accepted 2026-10-02:** R9 restated as a box of 35 kg or less when lifted with the trays and deck taken out, and the box labelled to be emptied before lifting. |

## Consequences

- `design_state: constructable` in `project.yaml`. The build plan DWD-BLD-001 shows every component and step in pictures generated from the model (`cad/src/build_plan_media.py`).
- Cost is reported against the value-engineering target: USD 520 (a hypothetical control target, not a limit) against an estimated USD 639 for the constructable design, USD 119 over (USD 620 as first made buildable, plus USD 19 for the 130 °C glazing sheet and the lifting label decided on 2026-10-02); the register lists cost drivers and savings worth trying.
- Requirement status (DWD-CAL-001 v0.7): 10 met, 1 over its value-engineering target (R11, by $119), 2 not verifiable at TRL 3 (R6, R10). With A2 accepted, R9 is restated as a box of 35 kg or less when lifted with the trays and deck taken out, and is met at 23.4 kg (it was not met by 0.2 kg as first written); the box carries a label to empty it before lifting (DWD-REQ-001).
- The appearance model `cad/src/product_model.py` now follows the constructable design (stand, lid, deck, flaps, pole and electronics from `cad/src/model.py`). The photoreal renders (`media/render-*.png`), `media/card.png` and `media/social-preview.png` are made from it on Amish's Mac, where Blender is.
- Open decisions, and the items to confirm when parts are bought, are kept in the design decisions register (`docs/06-design-decisions.md`, DWD-DEC-001).

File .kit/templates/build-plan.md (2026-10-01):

---
doc_id: PRJ-BLD-001
title: Project prototype build plan
project: Project name
doc_type: Build plan
version: "0.1"
status: Draft
date: YYYY-MM-DD
author: Amish Chadha
license: CERN-OHL-S-2.0
revisions:
  - version: "0.1"
    date: YYYY-MM-DD
    author: Amish Chadha
    change: First build plan; design made constructable
---

# Project prototype build plan

**Plan, not yet built.** How to build the first proof-of-concept prototype, component by component. Building and testing to it is TRL 4 work. Decisions still to be made are kept in the design decisions register (`docs/06-design-decisions.md`), not here.

## 1. What you are building

Every component, pulled apart and numbered in build order

One short paragraph: what the prototype is, how many components, which are made and which are bought, and the main ways they are made.

## 2. What changed to make it buildable

| Component | The concept had | The buildable design has | Why |
| --- | --- | --- | --- |

## 3. Making the components

### 3.1 Component name

Making sketch

**What it is and what it is made from.**

**How to make it.**

1. Mark out ...
2. Cut ...

**How it fits the parts next to it.**

Close-up of the joint

**Check before moving on.**

## 4. Putting it together

### Step 1: ...

Step 1

## 5. First checks

| Check | Requirement | How | Pass when |
| --- | --- | --- | --- |

## 6. Safety stops

## 7. Tools, skills and workspace

## 8. Where the numbers come from

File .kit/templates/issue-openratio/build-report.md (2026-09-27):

---
name: Build report
about: Tell us what happened when you built, printed or tested part of this design
title: "Build report: "
labels: build-report
---

This is a research and educational prototype, not a medical device. It is a TRL 3 concept and is not released for fabrication. If you build any part of it, you do so at your own risk. Reports help everyone.

**What you built** (part, sub-assembly or test)

**Materials, tools and settings**

**What worked**

**What did not work, with photos or measurements if you have them**

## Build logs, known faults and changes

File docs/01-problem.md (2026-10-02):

---
doc_id: DWD-PRB-001
title: DewDrive problem statement
project: DewDrive
doc_type: Problem statement
version: "0.7"
status: Draft
date: '2026-10-02'
author: Amish Chadha
license: CERN-OHL-S-2.0
revisions:
- version: "0.1"
  date: '2026-09-24'
  author: Amish Chadha
  change: Initial scaffold
- version: "0.2"
  date: '2026-09-25'
  author: Amish Chadha
  change: Populate to TRL 2 (problem, users, context, constraints, out of scope, prior work with sources, open questions)
- version: "0.3"
  date: '2026-09-25'
  author: Amish Chadha
  change: TRL 3 update (budget and problem wording decided by Amish in DWD-DDR-001; yield figures from DWD-CAL-001; partner question still open)
- version: "0.4"
  date: '2026-09-25'
  author: Amish Chadha
  change: Recommendations accepted by Amish (DDR-002); yield and cost figures from DWD-CAL-001 v0.2
- version: "0.5"
  date: '2026-09-26'
  author: Amish Chadha
  change: Budget top-up approved by Amish
- version: "0.6"
  date: '2026-10-01'
  author: Amish Chadha
  change: Budget treated as a value-engineering target
- version: "0.7"
  date: '2026-10-02'
  author: Amish Chadha
  change: First partner type and region decided on 2026-10-02 (DWD-DEC-001, item 5)
---

# DewDrive problem statement

Arid households without surface water or groundwater within reach depend on carried or trucked water; the air above them is an untapped supplementary source. A small, open, solar-powered harvester could turn that moisture into a daily supplement of drinking water, but the physics limits it to well under a litre per square metre per day in dry air (DWD-CAL-001 v0.2 estimates about 0.57 L per day for the design decided on 2026-09-25, with night air drawn through the sorbent trays), so the realistic aim is a supplementary drinking-water source that a household or school can build and repair, not a replacement for a well or a water truck. Design with, not for: requirements must come from co-design sessions and field trials with the intended users through a local partner.

## The problem

Where there is no river, spring or aquifer within reach, water is carried from far away, bought from vendors or trucked in, and it is often of uncertain quality. The World Health Organization puts survival needs for drinking and food at 2.5 to 3 L per person per day, and basic needs including hygiene and cooking at 7.5 to 15 L ([WHO technical note 9](https://cdn.who.int/media/docs/default-source/wash-documents/who-tn-09-how-much-water-is-needed.pdf)).

Even desert air holds water. At 20 °C and 40 % relative humidity (RH), each cubic metre carries about 7 g of vapour. Field trials in Scottsdale, Arizona, recorded night RH of about 40 % falling to 8 % by day ([Fathieh et al., *Science Advances*, 2018](https://www.science.org/doi/10.1126/sciadv.aat3198); [ScienceDaily summary](https://www.sciencedaily.com/releases/2018/06/180608200143.htm)). Cooling air below its dew point, as a fog net or a refrigeration dehumidifier does, fails at this humidity or costs too much energy. A desiccant can instead soak up vapour from cool, relatively humid night air, and the sun can drive it out again by day into a condenser.

Three gaps keep this from reaching the people who need it:

- **Cost and closed designs.** Commercial solar hydropanels produce about 3 to 5 L per day and cost about $2,000 each ([Forbes, 2022](https://www.forbes.com/sites/jeffkart/2022/01/13/solar-powered-source-hydropanels-can-produce-up-to-5-liters-of-drinking-water-per-day/)). They are sealed products that cannot be built or repaired locally.
- **Exotic sorbents.** Much of the research uses metal-organic frameworks (MOFs) or engineered zeolites that are not sold in small quantities at low cost.
- **Unclear real-world yield.** Published yields vary tenfold with humidity, sorbent and device design, so a household cannot tell whether a harvester would be worth building.

## Users and context

Table 1. Intended users (to be confirmed through co-design).

| User | Need | Context |
| --- | --- | --- |
| Rural household in an arid or semi-arid area | A daily supplement of safe drinking water, especially in the dry season | Water carried or bought; sun is plentiful; nights are cooler and more humid than days |
| School or clinic | Drinking water for children or patients when the delivered supply runs short | Some staff time for a twice-daily routine; roof or yard space |
| Local technician or maker | A design they can build from local materials and repair | Basic sheet-metal, woodwork and electronics skills |
| Researcher or NGO | Open, logged yield data across climates | Wants comparable measurements between sites |

Operating environment (proposed design envelope):

- Night air 10 to 30 °C at 25 to 70 % RH; day air 25 to 45 °C at 5 to 30 % RH.
- Clear-sky solar irradiation about 5 to 7 kWh/m² per day on a tilted surface (estimate for desert sites, to be confirmed with site data).
- Dust, wind to 20 m/s (72 km/h), ultraviolet exposure, animals and occasional rain.
- No grid power. The site may be visited only twice a day.

## Constraints

- Garage-buildable research prototype, a value-engineering target of $520 USD in parts (`project.yaml`; a hypothetical control target, not a limit; moved from $400 to $500 by Amish on 2026-09-25, DWD-DDR-001, D1, and to $520 on 2026-09-26, DWD-DDR-002, D15). The TRL 3 estimate was $515, within the target; after the design for construction it is $620, $100 over the target (DWD-DDR-003).
- Regeneration heat from the sun only. Any electricity (fan, logger) comes from the device's own small solar panel.
- Common, low-cost sorbents: silica gel and calcium chloride, both sold as desiccants and food-grade chemicals.
- Everything in contact with the water must be food-grade.
- Two people can carry and set it up without tools beyond a spanner and a screwdriver.
- Open hardware under CERN-OHL-S-2.0; software under MIT.

## Out of scope

- Providing all of a household's water. One unit is sized as a supplement (see DWD-REQ-001).
- Refrigeration or compressor-based dehumidifiers.
- MOF or other specialty sorbents in the first prototype (possible later upgrade).
- Treating the water to a certified potable standard. The design keeps the water clean in the device, but the documents require testing and treatment before drinking until tests show otherwise.

## Prior work

- **MOF harvesters.** Kim and colleagues showed solar-driven harvesting with MOF-801 at 20 % RH ([*Science*, 2017](https://doi.org/10.1126/science.aam8743)). The Arizona field trial produced about 0.2 L per kg of MOF-801 per day, and the aluminium-based MOF-303 was expected to double that at far lower material cost ([Fathieh et al., 2018](https://www.science.org/doi/10.1126/sciadv.aat3198)).
- **Dual-stage zeolite device.** LaPotin and colleagues at MIT reached about 0.77 L/m² per day outdoors with a dual-stage AQSOA Z01 device, at about 9 % thermal efficiency and absorber temperatures up to 94 °C, with overnight air at about 68 % RH ([*Joule*, 2021](https://www.sciencedirect.com/science/article/pii/S254243512030444X)).
- **Salt-in-silica composites.** Calcium chloride confined in mesoporous silica gel (SWS-1L) holds up to 0.6 to 0.7 g of water per gram ([Aristov et al., *Chemical Engineering Science*, 2006](https://www.sciencedirect.com/science/article/abs/pii/S0009250905007050)). A passive harvester with a lithium chloride and silica gel composite produced 355 g per day from 0.48 m² (about 0.74 L/m² per day), with 0.52 g/g uptake at 30 °C and 60 % RH ([Shao et al., *Energy*, 2024](https://www.sciencedirect.com/science/article/abs/pii/S0360544224016906)).
- **Salt in a polymer matrix.** An alginate-derived CaCl₂ composite took up its own weight in water at 10 mbar vapour pressure and released it at 100 to 150 °C ([Kallenberger and Fröba, *Communications Chemistry*, 2018](https://www.nature.com/articles/s42004-018-0028-9)).
- **Commercial hydropanels.** SOURCE hydropanels produce about 3 to 5 L per day per panel at about $2,000 each ([Forbes, 2022](https://www.forbes.com/sites/jeffkart/2022/01/13/solar-powered-source-hydropanels-can-produce-up-to-5-liters-of-drinking-water-per-day/)).

The gap DewDrive targets is an open, documented and locally buildable device using the low-cost composite route, with logging built in so that yield can be compared between sites.

## Open questions

- [ ] What are the real night humidity and solar figures at the partner's site? The partner and region were decided by Amish on 2026-10-02 (DWD-DEC-001, item 5): the first candidate type to approach, not yet agreed, is a university dryland field station in a hot semi-arid region with night humidity of about 25 to 40 % and an existing weather record, with a water and sanitation NGO for the later community trial.
- [ ] Is about 0.5 L per day per unit worth a household's time and money, compared with carrying or buying water? DWD-CAL-001 v0.2 puts the parts cost at about $0.49 per litre over five years.
- [ ] How will households test and treat the water, and who pays for the tests?
- [ ] Would a school or clinic, with staff on site twice a day, be a better first user than a household?

> **Safety:** Harvested water must be tested and treated before drinking. Calcium chloride is an eye and skin irritant, and the box interior runs hot enough to burn. See the safety section of DWD-PRC-001.

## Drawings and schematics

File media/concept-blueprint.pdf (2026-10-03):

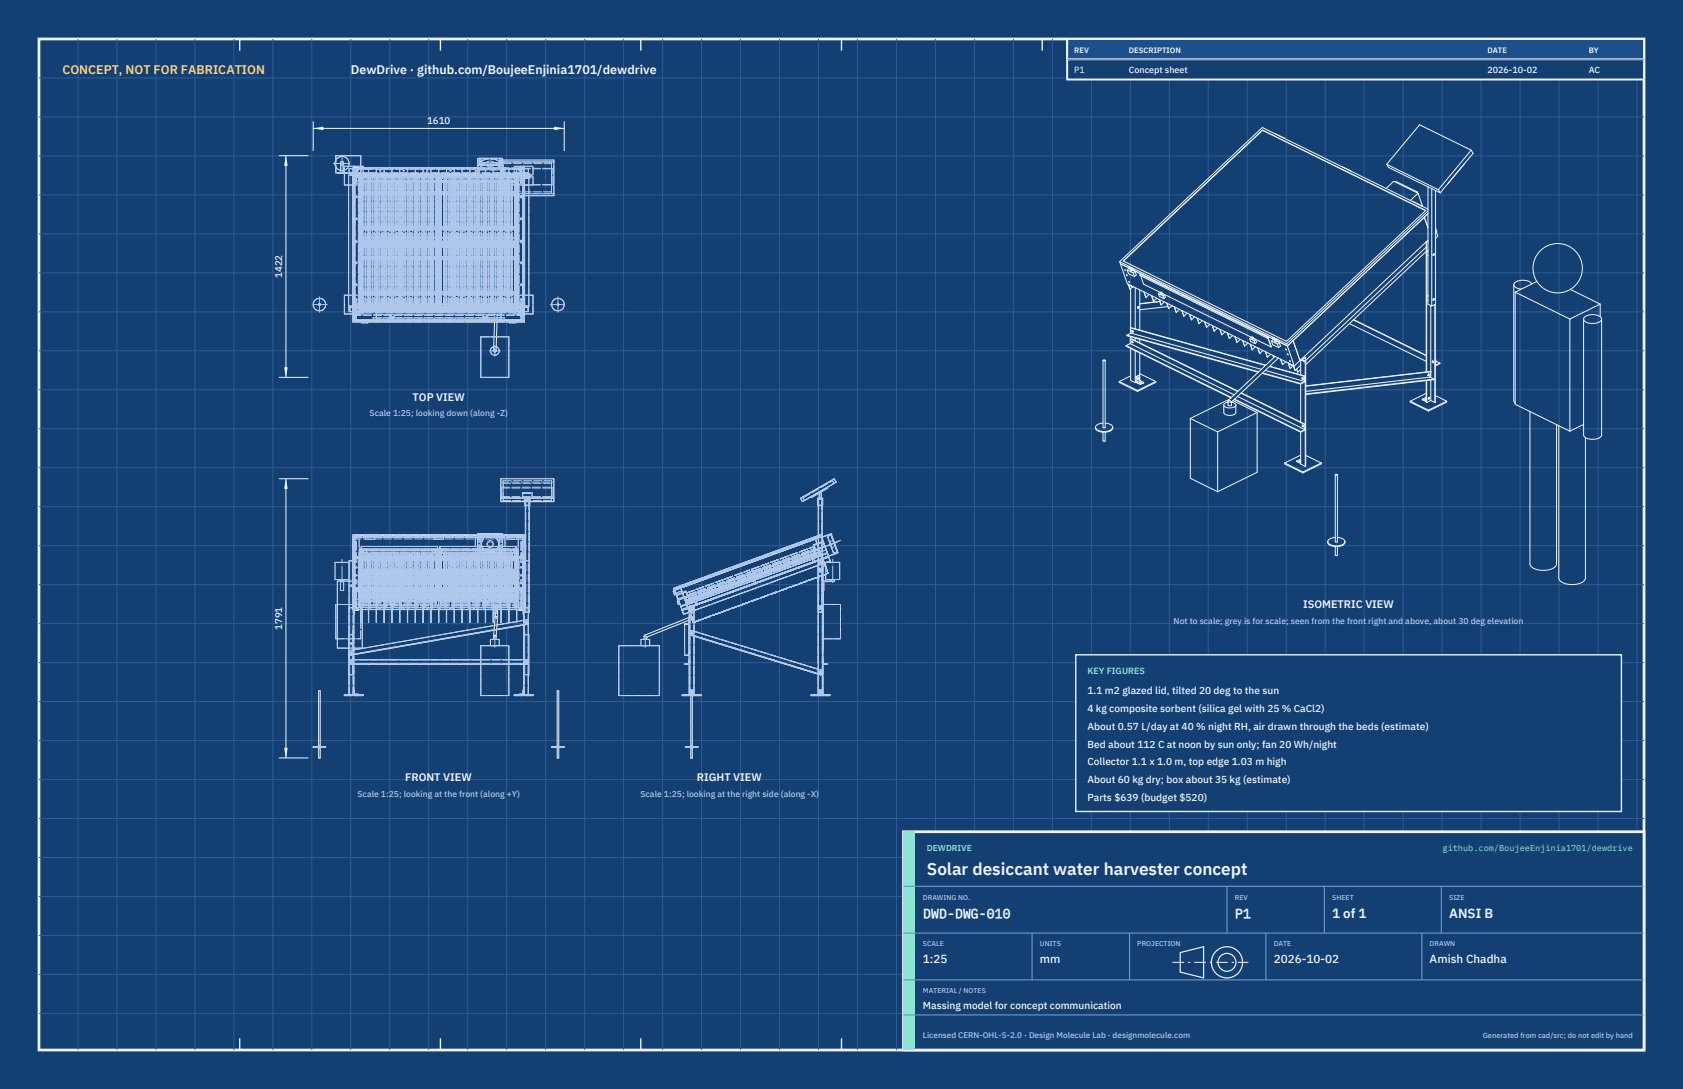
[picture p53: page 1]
CONCEPT, NOT FOR FABRICATION; DewDrive · github.com/BoujeeEnjinia1701/dewdrive; FRONT VIEW; TOP VIEW; RIGHT VIEW; ISOMETRIC VIEW; REV; DESCRIPTION; DATE; Concept sheet; DEWDRIVE; github.com/BoujeeEnjinia1701/dewdrive; DRAWING NO. DWD-DWG-010; REV P1; SHEET 1 of 1; SIZE ANSI B; SCALE 1:25; UNITS mm; PROJECTION; DRAWN Amish Chadha; Licensed CERN-OHL-S-2.0 · Design Molecule Lab · designmolecule.com; Generated from cad/src; do not edit by hand

Scale 1:25; looking down (along -Z)

Not to scale; grey is for scale; seen from the front right and above, about 30 deg elevation

KEY FIGURES
1.1 m2 glazed lid, tilted 20 deg to the sun
4 kg composite sorbent (silica gel with 25 % CaCl2)
About 0.57 L/day at 40 % night RH, air drawn through the beds (estimate)
Bed about 112 C at noon by sun only; fan 20 Wh/night
Collector 1.1 x 1.0 m, top edge 1.03 m high
About 60 kg dry; box about 35 kg (estimate)
Parts $639 (budget $520)

Scale 1:25; looking at the front (along +Y)

Scale 1:25; looking at the right side (along -X)

Solar desiccant water harvester concept

MATERIAL / NOTES
Massing model for concept communication

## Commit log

2026-09-24 Initial scaffold: standard open hardware layout, CERN-OHL-S v2 + MIT licenses
    Claude-Session: https://claude.ai/code/session_01XuhhSU4W6fYhgCfURbrkut
    [bom.csv]
2026-09-25 Adopt portfolio kit v1.3.0: session commands, scale figure, 3D viewer, flow diagrams
    Adds .claude/commands (/populate, /advance-trl3, /rein-in, /refresh-media)
    so every Claude Code session starts from the standard prompts, and extends
    concept media with a 1.75 m scale figure, an interactive glTF viewer and
    system or energy flow diagrams. TRL cap 3 unchanged.
    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
2026-09-25 Kit v1.3.1: renderer fixes from the TremorTrace pilot
    Context scale parts for small objects, cutaway exclusions, and text
    labels in flow diagrams.
    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
2026-09-25 Populate dewdrive to a strong TRL 2 with concept media (batch 6)
    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
    [bom.csv]
2026-09-25 Advance dewdrive to TRL 3 (batches 5 and 6)
    Decisions approved by Amish 2026-09-25 recorded in DDR-001. TRL 4 is on hold.
    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
    [bom.csv, collector-box.step, collector-box.stl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]
2026-09-26 Accept all recommendations (DDR-002), switch footer to designmolecule.com, add README write-up with new inspiration point
    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
    [bom.csv, collector-box.step, collector-box.stl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]
2026-09-26 Strengthen sources, apply approved budgets, add CITATION.cff and CONTRIBUTORS.md with credits
    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
    [results.csv]
2026-09-27 Product appearance model and photoreal renders
    Adds cad/src/product_model.py (appearance model for renders only, all main
    dimensions from model.py) and Blender renders in media/render-*.png,
    captioned with the project, repository and viewing direction. README leads
    with the product render; trl stays 3.
    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
2026-10-01 Image quality pass: legible exploded views, flow diagrams and drawing sheets
    Kit 1.6.1 image layout: the parts list sits in its own column, number bubbles sit on visible parts and never overlap, small parts get a leader, pictures are cropped to the subject, flow labels keep numbers with their units, and sheet captions and the revision table no longer overprint. Concept images, blueprint and general arrangement sheet regenerated; repo-specific labels moved clear of other text and lines.
2026-10-01 Kit 1.7.0: constructable design, illustrated build plan and design decisions register
    The design is now constructable: every part can be made and fits its neighbours, with each change recorded in a Design for construction decision record (made under Amish's 2026-09-30 instruction; ope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
    [bom.csv, collector-box.step, collector-box.stl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]
2026-10-01 Budget treated as a value-engineering target
    Amish, 2026-10-01: the budget is a hypothetical control target that keeps the design on a value-engineering lens, not a spending limit. Documents now state the value-engineering target and the estima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
2026-10-02 Record Amish's approval of the open-decision recommendations
    Amish approved the recommendation on every open decision in the design decisions register ("i approve your recommendations for all 555 open decisions.", 2026-10-02). Each decision is moved to Decisio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
2026-10-03 Carry approved follow-ups into the design and redo photoreal renders
    Amish approved the follow-up actions from the open-decision sign-off ("APPROVED CHANGES, COMPLETE THESE", 2026-10-02), the design-for-construction change tables in ten repos, the last wave's open dec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
    [bom.csv, collector-box.step, condenser.step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]
2026-10-28 Kit 1.9.1 upgrade: pipeline documents and detailed CAD for every option
    Kit 1.9.1 installed (.kit, CLAUDE.md, .claude/commands). Kit 1.8 pipeline: STEM check with fixes under the 2026-10-23 standing instruction, concept options with the current design as option A, URS, PRS, generated RTM, REG, FEA, RSK with design FMEA, MKT, PLN and DDR; kit 1.9 D3 model of every option passing cad/fidelity.json; independent review recorded in the STEM check. Amish's 2026-10-25 decisions recorded where he approved a recommendation; all others proposed, awaiting Amish. Product renders and the options picture follow in a later commit where not yet included.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
2026-10-29 Add Cycles product renders and the concept options picture
    Blender Cycles renders of the kit 1.9.1 model, rendered on Amish's Mac and captioned; media/options.png from the D3 option models (this also clears the failing docs check, which needs the picture); cards and PDFs rebuilt. The options picture labels option A as the current design unless project.yaml records Amish's choice.
2026-10-29 Add the concept options picture rendered from the D3 option models
    media/options.png from Blender Cycles panels of every option, rendered on Amish's Mac; the label reads CURRENT DESIGN unless project.yaml records Amish's choice. Clears the docs check, which needs th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

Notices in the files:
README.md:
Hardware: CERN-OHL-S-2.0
